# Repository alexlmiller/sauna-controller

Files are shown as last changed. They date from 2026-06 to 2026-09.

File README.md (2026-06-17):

# Local & Smart Sauna Controller

Open-source sauna convenience control built around ESPHome and Home Assistant. Control your sauna from anywhere with no cloud dependencies or crappy apps and for 1/3rd the cost of the normal commercial units.

The project can be built two ways:

- **Build from components**: hand-wire off-the-shelf modules and DIN parts.
- **Build with the carrier PCB**: use the Rev B control board PCB for cleaner
  wiring and integrated low-voltage distribution.

Both current build paths use the same Rev B firmware and pin map. The optional
wall panel uses an Elecrow CrowPanel 2.1" rotary display over a short wired UART
link, with a WiFi/Home Assistant panel target available for desk testing.

## Safety

This project is for **convenience control only**. It is not a primary safety
system and must not replace the sauna heater's listed safety controls.

- Use only properly rated, UL/ETL/listed components where applicable.
- Use a heater that already has its required high-limit and safety systems.
- Have the enclosure, high-voltage wiring, grounding, overcurrent protection,
  conductor sizing, strain relief, and final installation reviewed and installed
  by a qualified electrician.
- Do not rely on ESPHome, Home Assistant, WiFi, the wall panel, or this PCB as
  life-safety equipment.

Read [`docs/SAFETY.md`](docs/SAFETY.md) before building.

Controller Box

## What It Controls

- Heater contactor with a 24 VDC coil
- Two DS18B20 temperature probes: ceiling and bench
- Door reed switch
- Manual-reset high-temp circuit in series with the contactor coil
- Relay feedback contact for welded/failed relay detection
- 24 V RGBW LED strip through four PWM MOSFET channels
- Optional wall panel over direct 3.3 V UART

## User Interface

The controller exposes its entities through Home Assistant and can also be used
from a phone dashboard or the optional wall panel.

### Home Assistant Device Page

Home Assistant device page

### Phone Dashboard

Home Assistant phone dashboard

## Build Paths

### Option 1: Build From Components

Use an ESP32 DevKitC, MOSFET driver modules, opto input modules, DIN power
supplies, fusing/protection, and terminal blocks. This is best for prototyping
or a one-off hand-wired build.

Start here: [`docs/BUILD-FROM-COMPONENTS.md`](docs/BUILD-FROM-COMPONENTS.md)

### Option 2: Build With the Carrier PCB

Use the Rev B control board carrier PCB. This is the preferred path for new
installs because it reduces point-to-point wiring and integrates the ESP32
carrier, output drivers, opto inputs, PTC protection, 24 V distribution, 5 V
conversion, and field terminals.

Start here: [`docs/BUILD-WITH-CARRIER-PCB.md`](docs/BUILD-WITH-CARRIER-PCB.md)

The design philosophy and current hardware rationale are summarized in
[`docs/DESIGN.md`](docs/DESIGN.md).

## Firmware

Current build targets:

```bash
# Control board
esphome run firmware/control-board/rev-b.yaml

# Normal wired wall panel
esphome run firmware/wall-panel/wired.yaml

# WiFi/Home Assistant wall panel for desk testing
esphome run firmware/wall-panel/wifi.yaml
```

See [`docs/FIRMWARE.md`](docs/FIRMWARE.md) for secrets setup, target layout,
and the legacy Rev A note.

## Wall Panel

The wall panel is optional. The normal installation uses direct 3.3 V UART over
a short Cat5e run and gets 5 V power from the control board. The control board
remains the source of truth for temperature, faults, heat mode, and lighting.

See [`docs/WALL-PANEL.md`](docs/WALL-PANEL.md).

## More Detail

- [`docs/DESIGN.md`](docs/DESIGN.md): design choices and source-of-truth paths.
- [`docs/SAFETY.md`](docs/SAFETY.md): safety boundaries and installation notes.
- [`docs/FIRMWARE.md`](docs/FIRMWARE.md): ESPHome targets and package layout.
- [`docs/WALL-PANEL.md`](docs/WALL-PANEL.md): optional panel behavior and wiring.
- [`pcb/rev-b/README.md`](pcb/rev-b/README.md): KiCad, fabrication, assembly,
  and board verification details.

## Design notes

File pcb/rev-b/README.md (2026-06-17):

# Rev B Control Board PCB

Complete KiCad design for the Rev B sauna control board. The board carries an
ESP32 DevKitC V4, switches the low-voltage outputs, senses the low-voltage
inputs, distributes 24 V/5 V, and terminates the field wiring cleanly.

This board is part of a **convenience-control** project only. It does not
replace the heater's listed safety systems, required high-limit controls,
proper overcurrent protection, grounding, or code-compliant high-voltage
installation. Use UL/ETL/listed components where applicable and have the final
enclosure and wiring reviewed and installed by a qualified electrician.

For installation-level instructions, start with
[`../../docs/BUILD-WITH-CARRIER-PCB.md`](../../docs/BUILD-WITH-CARRIER-PCB.md).
For design rationale, see [`../../docs/DESIGN.md`](../../docs/DESIGN.md).

## Board Summary

- 120.76 x 88 mm, 2-layer, 1 oz outer copper, 5 mm corner radius, 4x M3 corner
  holes.
- ESP32 DevKitC V4 socket, using ESP32-WROOM-32E or ESP32-WROOM-32D only. Do
  not use WROVER DevKitC variants because Rev B uses GPIO16/GPIO17.
- 24 V input distribution, 24 V to 5 V conversion, and resettable PTC branch
  protection.
- Low-side MOSFET outputs for relay coil, RGBW LEDs, and optional AUX output
  hardware.
- Opto-isolated relay-feedback and high-temp status inputs.
- Separate DS18B20 buses for bench and ceiling sensors.
- Direct 3.3 V UART wall-panel connector with 5 V panel power.

## Connector Layout

The placement follows the cabinet wiring:

| Edge | Connectors | Reason |
|---|---|---|
| Top | `J_PWR`, `J_AUX_OUT` | 24 V PSU is above the board; AUX output can route with top-side low-voltage wiring |
| Left | `J_LED` | LED branch is the highest current low-voltage path, kept short |
| Bottom | `J_PANEL`, `J_DOOR`, `J_BENCH`, `J_CEILING`, `J_SRL250` | Sauna-room and panel wiring enters along the lower side |
| Right | `J_COIL`, `J_RELAY_FB` | Contactor sits to the right, so coil and monitor wiring stay short |

## Key Electrical Choices

- The contactor coil is low-side switched on the board, but heater power stays
  on the external contactor.
- The manual-reset high-temp loop is in series with the contactor coil and is
  also sensed through an opto input.
- Relay feedback uses the contactor auxiliary contact through an opto input.
- RGBW LED outputs are low-side switched and include gate-sensed activity LEDs.
- The optional AUX output is exposed by Rev B firmware as `AUX Output`.
- The on-board FAULT LED follows the firmware's latched fault state.
- The 5 V rail uses a K7805-2000R3 SIP-3 buck converter.
- The board uses a B.Cu ground plane and net classes defined in
  [`tools/design.py`](tools/design.py).

## Files

| File | Purpose |
|---|---|
| `sauna-rev-b.kicad_pro` | KiCad project and design rules |
| `sauna-rev-b.kicad_sch` | Generated schematic |
| `sauna-rev-b.kicad_pcb` | Hand-routed board generated from source plus captured routing |
| `tools/design.py` | Source of truth for nets, parts, pin mapping, and placement |
| `tools/routing.py` | Captured KiCad routing |
| `tools/footprints.py` | Local footprint geometry |
| `tools/generate_schematic.py` | Regenerates the schematic |
| `tools/generate_board.py` | Regenerates the PCB from design data and routing |
| `tools/import_routing.py` | Captures hand-routed traces from KiCad |
| `tools/generate_bom.py` | Regenerates assembly BOM |
| `tools/export_fabrication.py` | Regenerates BOM, CPL, Gerbers, drills, and upload zip |
| `tools/_repro_check.py` | Verifies generated board content matches the checked-in PCB |
| `tools/check_board.py` | Checks clearances and connectivity |
| `fabrication/` | Current fabrication and assembly outputs |

## Edit Workflow

Routing and final placement are edited in KiCad, then captured back into the
generator inputs. After KiCad edits:

```bash
cd pcb/rev-b
python3 -m venv .venv && .venv/bin/pip install kiutils numpy
.venv/bin/python tools/import_routing.py
.venv/bin/python tools/_design_diff.py
.venv/bin/python tools/_silk_diff.py
.venv/bin/python tools/_repro_check.py
.venv/bin/python tools/generate_board.py
.venv/bin/python tools/check_board.py
```

Before ordering, also run KiCad ERC/DRC locally with zones filled.

## Assembly Notes

The Rev B board is intended to be supplier-assembled, including terminal blocks,
ESP sockets, electrolytics, K7805 buck, and resettable PTCs. The generated
assembly files are in [`fabrication/`](fabrication/).

Current notable JLC/LCSC selections include:

- AOD4184A MOSFETs: `C99124`
- SS54 Schottky diodes: `C22452`
- SMBJ30CA TVS diodes: `C5331115`
- F1 LED PTC: `C719172`
- F4 AUX PTC: `C139284`

Verify stock, polarity, substitutions, and physical fit before ordering. Print
the board 1:1 and test-fit the DevKitC, terminal blocks, PTCs, K7805, SOP-4
opto parts, and electrolytic capacitors.

## Verification

Machine checks in this repo cover courtyard overlaps, board boundary, antenna
keepout, per-net-class copper/edge clearance, and single-island connectivity.

Before installing a fabricated board:

1. Inspect polarity, soldering, terminal labels, and ESP32 orientation.
2. Confirm 24 V input, 5 V output, and 3.3 V ESP rail with no field loads.
3. Bench-test relay-feedback and high-temp opto channels with 24 V.
4. Test each LED channel with a current-limited load.
5. Test contactor coil control before energizing the heater circuit.

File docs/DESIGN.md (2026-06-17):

# Design Notes

This file captures the durable design rationale for the current sauna
controller. It intentionally avoids copying large YAML or KiCad details; the
live source files listed below are authoritative.

## Source Of Truth

- Control board firmware: [`../firmware/control-board/rev-b.yaml`](../firmware/control-board/rev-b.yaml)
- Shared control logic: [`../firmware/control-board/packages/common.yaml`](../firmware/control-board/packages/common.yaml)
- Wall panel firmware: [`../firmware/wall-panel/`](../firmware/wall-panel/)
- Rev B board design: [`../pcb/rev-b/`](../pcb/rev-b/)
- Rev B board database: [`../pcb/rev-b/tools/design.py`](../pcb/rev-b/tools/design.py)

## Safety Boundary

The project is for convenience control only. The heater must have its own
listed safety systems, and the manual-reset high-temp loop stays in series with
the contactor coil so it can interrupt heat without software.

The control board should fail with heat off if the ESP32 reboots, firmware
crashes, WiFi drops, Home Assistant is unavailable, or the wall panel is
unplugged. That fail-off behavior is useful, but it is not a substitute for a
listed safety system or code-compliant installation.

## Hardware Philosophy

- Keep high-voltage switching outside the PCB. The board controls a 24 VDC
  contactor coil; the contactor handles heater power.
- Use a 24 V low-voltage cabinet bus for field wiring, contactor coil, opto
  wetting loops, LED strip power, and auxiliary loads.
- Generate 5 V on the carrier board for the ESP32 DevKitC and optional wall
  panel.
- Keep the ESP32 as a socketed DevKitC module instead of placing the ESP32
  module directly on the carrier board. This avoids RF layout, USB, boot strap,
  and assembly complexity.
- Use the Espressif ESP32-DevKitC V4 with an ESP32-WROOM-32E or WROOM-32D
  module. Do not use WROVER DevKitC variants on Rev B because GPIO16/GPIO17 are
  used by the board.
- Prefer grouped, field-serviceable connectors over minimum board area. The
  connector placement follows the physical cabinet: 24 V supply at the top,
  sauna-room wiring along the bottom, LEDs on the left, and contactor wiring on
  the right.
- Use resettable PTC protection on the low-voltage board branches instead of
  external DIN fuse holders.

## Control Model

The control board owns the heater, faults, sensors, and outputs. Home Assistant
and the wall panel request state changes; they are not required for the board to
run its local control logic.

The wall panel is a client. On boot it syncs from the control board before
publishing user changes, so it does not overwrite Home Assistant or control
board state with stale defaults.

## Current GPIO Map

The authoritative map is the `substitutions:` block in
[`../firmware/control-board/rev-b.yaml`](../firmware/control-board/rev-b.yaml).
For a hand-wired build, wire to that file rather than an older Rev A pin list.

Rev B uses:

| Function | GPIO |
|---|---:|
| Relay coil MOSFET | 23 |
| LED R/G/B/W | 19 / 18 / 17 / 16 |
| Door reed | 25 |
| Bench / ceiling DS18B20 | 26 / 27 |
| Relay feedback | 34 |
| High-temp trip status | 35 |
| Wall panel UART TX / RX | 32 / 33 |
| Fault LED | 22 |
| AUX output | 4 |

GPIO34 and GPIO35 are input-only and do not have internal pull-ups. The Rev B
carrier provides the required input conditioning; a hand-wired component build
must do the same.

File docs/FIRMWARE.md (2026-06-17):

# Firmware

Current builds use the Rev B firmware targets.

## Targets

```bash
# Control board
esphome run firmware/control-board/rev-b.yaml

# Wired wall panel
esphome run firmware/wall-panel/wired.yaml

# WiFi/Home Assistant wall panel for desk testing
esphome run firmware/wall-panel/wifi.yaml
```

## Secrets

Create a root `secrets.yaml` with:

```yaml
wifi_ssid: "..."
wifi_password: "..."
wifi_fallback_pw: "..."
ota_password: "..."
api_key: "..."
syslog_host: "..."
```

The firmware folders contain relative `secrets.yaml` symlinks so ESPHome can
resolve `!secret` after the targets were moved into subdirectories. The real
root `secrets.yaml` is ignored by Git.

## Control Board Pins

The current pin map lives in the `substitutions:` block of
[`../firmware/control-board/rev-b.yaml`](../firmware/control-board/rev-b.yaml).
That file is the source of truth for both carrier-PCB and hand-wired Rev B
builds.

Rev B deliberately changed several Rev A pins to make the board route cleanly:
the relay coil is on GPIO23, the wall-panel UART is on GPIO32/GPIO33, the door
input is on GPIO25, relay feedback and high-temp status are on GPIO34/GPIO35,
and the RGBW LED channels are ordered GPIO19/GPIO18/GPIO17/GPIO16.

Rev B also includes [`../firmware/control-board/packages/rev-b-hardware.yaml`](../firmware/control-board/packages/rev-b-hardware.yaml),
which drives the on-board FAULT LED from GPIO22 and exposes GPIO4 as the
`AUX Output` switch. That package is included only by the Rev B control-board
target.

## Layout

```text
firmware/
  control-board/
    rev-b.yaml
    packages/common.yaml

  wall-panel/
    wired.yaml
    wifi.yaml
    packages/

  legacy/rev-a/
```

The control board owns safety and actuator control. The wall panel sends
requests and displays status but is not required for safe operation.

## Legacy Rev A

Rev A firmware wrappers are kept in [`firmware/legacy/rev-a/`](../firmware/legacy/rev-a/)
for early boards only. New component and carrier-PCB builds should use Rev B.

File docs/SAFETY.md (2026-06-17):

# Safety

This project is for **convenience control only**. It can command a contactor,
read sensors, manage lighting, and expose controls through Home Assistant or a
wall panel. It is not a primary safety system.

## Requirements

- Use a sauna heater that already includes its required safety systems.
- Keep the heater's listed/manual-reset high-limit and required thermal
  protections in place.
- Use UL/ETL/listed components where applicable, including the contactor, power
  supply, enclosure, terminal blocks, fuses/breakers, conductors, and glands.
- Size conductors, fuses, breakers, contactors, terminals, and enclosures for
  the actual heater load and installation environment.
- Keep high-voltage and low-voltage wiring physically separated.
- Bond and ground the enclosure and heater according to local code.
- Have the final design, enclosure, wiring, overcurrent protection, grounding,
  and installation reviewed and installed by a qualified electrician.

## Do Not Rely On

Do not rely on any of the following as life-safety equipment:

- ESPHome firmware
- Home Assistant
- WiFi
- The wall panel
- The custom carrier PCB
- Software temperature limits
- Relay feedback monitoring

The manual-reset high-temp loop and the heater's own listed safety systems must
remain the safety backstop.

## Design Intent

The control board should fail with the heater off when the ESP32 reboots,
firmware crashes, WiFi drops, Home Assistant is unavailable, or the wall panel
is unplugged. That fail-off behavior is useful, but it still does not make the
project a code-approved primary safety system.

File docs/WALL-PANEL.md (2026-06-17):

# Wall Panel

The wall panel is an optional local interface based on the Elecrow CrowPanel
2.1" rotary display. It is not the safety controller; the control board remains
the source of truth.

## Normal Wired Build

- Direct 3.3 V UART over a short Cat5e run
- Control board UART: GPIO32 TX / GPIO33 RX
- Wall panel UART: GPIO43 TX / GPIO44 RX
- 5 V power from the control board
- WiFi remains available for OTA updates

Firmware:

```bash
esphome run firmware/wall-panel/wired.yaml
```

## WiFi Desk-Test Build

The WiFi/Home Assistant target is useful for UI testing without the wired UART
link:

```bash
esphome run firmware/wall-panel/wifi.yaml
```

## Behavior

- Heater page: current temperature, target temperature, heater state, fault
  banner.
- Lights page: brightness and preset control.
- Status page: ceiling/bench temperatures, door, heater, high-temp, relay
  feedback, and clear-fault control.

## Control Model

The control board remains authoritative. The panel displays exported control
board state and sends commands for target temperature, heat mode, lights, and
fault clearing.

The panel suppresses command publishing until it has synced from the control
board, so it should not overwrite Home Assistant changes on boot. The live
implementation is in:

- [`../firmware/wall-panel/packages/common.yaml`](../firmware/wall-panel/packages/common.yaml)
- [`../firmware/wall-panel/packages/wired.yaml`](../firmware/wall-panel/packages/wired.yaml)
- [`../firmware/wall-panel/packages/wifi.yaml`](../firmware/wall-panel/packages/wifi.yaml)
- [`../firmware/control-board/packages/common.yaml`](../firmware/control-board/packages/common.yaml)

## UART Notes

The installed Rev B design uses direct 3.3 V UART, not RS-485. That choice keeps
the panel wiring simple and has been sufficient for the short in-cabinet to
wall-panel run. Revisit RS-485 only if the direct UART link proves unreliable in
a specific installation.

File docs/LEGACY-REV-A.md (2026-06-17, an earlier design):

# Legacy Rev A

Rev A was an early board/hand-wired compatibility target. It is kept only for
the few existing early systems.

New builds should use:

- [`firmware/control-board/rev-b.yaml`](../firmware/control-board/rev-b.yaml)
- [`firmware/wall-panel/wired.yaml`](../firmware/wall-panel/wired.yaml)
- [`firmware/wall-panel/wifi.yaml`](../firmware/wall-panel/wifi.yaml)

Legacy files:

- [`firmware/legacy/rev-a/control-board.yaml`](../firmware/legacy/rev-a/control-board.yaml)
- [`firmware/legacy/rev-a/wall-panel-wired.yaml`](../firmware/legacy/rev-a/wall-panel-wired.yaml)
- [`firmware/legacy/rev-a/wall-panel-wifi.yaml`](../firmware/legacy/rev-a/wall-panel-wifi.yaml)

Do not use these for a new self-assembled or carrier-PCB build unless you are
intentionally matching an existing Rev A installation.

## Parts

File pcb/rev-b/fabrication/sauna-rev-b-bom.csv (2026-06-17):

Comment | Designator | Footprint | JLCPCB Part #
ESP_ROW_3V3 | J_ESP1 | 1x19 2.54mm female header | C319202
ESP_ROW_GND23 | J_ESP2 | 1x19 2.54mm female header | C319202
100nF | C3,C5,C7,C8,C9,C10 | C0805 | C49678
10uF 50V | C1 | C1210 | C138687
22uF 25V | C2 | C1210 | C52306
GREEN 24V | LED1 | LED0805 | C2297
GREEN 5V | LED2 | LED0805 | C2297
RED ACT | LED4,LED5,LED6,LED7 | LED0805 | C2295
RED FAULT | LED3 | LED0805 | C2295
750mA PTC (COIL) | F2 | PTC1812 | C208467
750mA PTC (LOGIC) | F3 | PTC1812 | C208467
2A PTC (AUX) | F4 | PTC2920 | C139284
3A PTC (LED) | F1 | PTC2920 | C719172
100R | R7,R8,R9,R10,R11,R21,R22,R23,R24,R32 | R0805 | C17408
10K | R4,R5,R12,R13,R14,R15,R16,R17,R25,R33 | R0805 | C17414
1K | R18,R26,R27,R28,R29,R30,R31 | R0805 | C17513
4K7 | R19,R20 | R0805 | C17673
3K3 | R1,R2 | R1206 | C104771
750mA PTC | PF1 | R1812 | C208467
220uF 50V | C4,C6 | Radial D8.0mm P3.50mm | C106658
K7805-2000R3 | U1 | SIP-3,2.54mm | C18212380
SS54 | D5,D11 | SMA,DO-214AC | C22452
SMBJ30CA | D2,D3 | SMB,DO-214AA | C5331115
SMBJ33A | D1 | SMB,DO-214AA | C78419
1N4148WS | D9,D10 | SOD-323 | C2128
ESD9B5.0 | D6,D7,D8 | SOD-923 | C111566
LTV-817S | OPT_RELAY_FB,OPT2 | SOP-4 | C109227
USBLC6-2SC6 | U2 | SOT-23-6 | C7519
AOD4184A | Q1,Q2,Q3,Q4,Q5,Q6 | TO-252-2,DPAK | C99124
24V_IN | J_PWR | Terminal 5.08mm 2P | C8461
AUX_OUT | J_AUX_OUT | Terminal 5.08mm 2P | C8461
COIL | J_COIL | Terminal 5.08mm 2P | C8461
DOOR | J_DOOR | Terminal 5.08mm 2P | C8461
RELAY_FB | J_RELAY_FB | Terminal 5.08mm 2P | C8461
SRL250 | J_SRL250 | Terminal 5.08mm 2P | C8461
BENCH_T | J_BENCH | Terminal 5.08mm 3P | C8438
CEIL_T | J_CEILING | Terminal 5.08mm 3P | C8438
PANEL | J_PANEL | Terminal 5.08mm 4P | C8429
LED_RGBW | J_LED | Terminal 5.08mm 5P | C8433

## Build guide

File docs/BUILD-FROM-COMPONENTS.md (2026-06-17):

# Build From Components

This path builds the sauna controller from off-the-shelf modules and DIN parts
instead of the custom carrier PCB. It is useful for prototyping or a one-off
hand-wired build.

New component builds should still use the **Rev B firmware and GPIO map** in
[`firmware/control-board/rev-b.yaml`](../firmware/control-board/rev-b.yaml).
Rev A files are only for early historical boards.

## Safety

This project is for **convenience control only**. Use a heater with its own
listed safety systems, keep the manual-reset high-temp protection in series with
the contactor coil, use UL/ETL/listed components where applicable, and have the
high-voltage wiring and final enclosure reviewed and installed by a qualified
electrician. Read [`SAFETY.md`](SAFETY.md) before building.

## What You Need

Core electronics:

- ESP32 DevKitC-32E with ESP32-WROOM-32E or ESP32-WROOM-32D module
- 24 V DIN power supply
- 24 V to 5 V DC-DC converter for ESP32 and optional wall panel power
- 5 MOSFET driver channels: relay coil, LED R, LED G, LED B, LED W
- 2 opto-isolated 24 V input channels: relay feedback and high-temp status
- 2 DS18B20 temperature probes
- Door reed switch
- Terminal blocks, wire ferrules, DIN rail wiring hardware, and strain relief
- Branch fusing or resettable protection sized for the loads

Sauna/load hardware:

- Properly rated heater contactor with 24 VDC coil
- Compatible auxiliary contact block for relay feedback
- Manual-reset high-temp thermostat, such as SUPCO SRL250
- 24 V RGBW LED strip, aluminum channel, diffuser, and high-temp cable
- Code-compliant enclosure and high-voltage terminal blocks

Optional:

- Elecrow CrowPanel 2.1" rotary display for the wall panel

## Low-Voltage Architecture

- The 24 V DIN supply feeds the contactor coil branch, LED branch, opto wetting
  loops, auxiliary branch if used, and 24 V to 5 V converter.
- The 5 V converter feeds ESP32 `VIN` and, if used, the wall panel.
- All low-voltage returns share a common 0 V reference.
- The contactor coil is switched on the low side by a MOSFET driver.
- RGBW strip channels are switched on the low side by MOSFET drivers.
- Relay feedback and high-temp status are sensed through opto-isolated 24 V
  input modules or equivalent discrete circuits.

## Rev B GPIO Map

Wire the component build to this map so it runs the current firmware. The
authoritative version is the `substitutions:` block in
[`../firmware/control-board/rev-b.yaml`](../firmware/control-board/rev-b.yaml).

| Function | GPIO |
|---|---:|
| Relay coil MOSFET | 23 |
| LED R/G/B/W | 19 / 18 / 17 / 16 |
| Door reed | 25 |
| Bench / ceiling DS18B20 | 26 / 27 |
| Relay feedback | 34 |
| High-temp trip status | 35 |
| Wall panel UART TX / RX | 32 / 33 |
| Fault LED | 22 |
| AUX output | 4 |

GPIO34 and GPIO35 are input-only and do not have internal pull-ups. Your opto
input circuits must provide the required pull-ups or output conditioning.
GPIO22 drives the fault LED, and GPIO4 drives the optional AUX low-side output.

## Wiring Notes

- Put the manual-reset high-temp thermostat in series with the contactor coil
  so it can interrupt heat without software.
- Add flyback suppression across the contactor coil or at the coil driver.
- Fuse/protect the LED branch, coil branch, logic branch, and any auxiliary
  branch based on the actual loads and wire sizes.
- Use shielded/twisted wiring for temperature probes where practical.
- Keep high-voltage wiring away from ESP32, sensor, panel, and low-voltage
  signal wiring.
- Label terminal blocks by function, not just GPIO number.

## Firmware

Flash the control board:

```bash
esphome run firmware/control-board/rev-b.yaml
```

Optional wall panel:

```bash
esphome run firmware/wall-panel/wired.yaml
```

See [`FIRMWARE.md`](FIRMWARE.md) and [`WALL-PANEL.md`](WALL-PANEL.md).

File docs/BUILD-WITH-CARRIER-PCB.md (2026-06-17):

# Build With the Carrier PCB

This is the preferred path for new installs. The Rev B control board carrier
PCB replaces most point-to-point low-voltage module wiring with one organized
board.

## Safety

This project is for **convenience control only**. Use a heater with its own
listed safety systems, keep the manual-reset high-temp protection in series with
the contactor coil, use UL/ETL/listed components where applicable, and have the
high-voltage wiring and final enclosure reviewed and installed by a qualified
electrician. Read [`SAFETY.md`](SAFETY.md) before building.

## What the PCB Includes

- ESP32 DevKitC-32E socket headers
- 24 V input distribution
- 24 V to 5 V conversion for ESP32 and wall panel
- MOSFET outputs for relay coil, RGBW LEDs, and optional AUX output hardware
- Opto inputs for relay feedback and high-temp status
- Resettable PTC branch protection
- DS18B20, door, wall-panel, LED, relay, and high-temp field terminals
- Power/status LEDs and test points

## What You Still Need

- Rev B control board from [`pcb/rev-b/`](../pcb/rev-b/)
- ESP32 DevKitC-32E with ESP32-WROOM-32E or ESP32-WROOM-32D module
- 24 V DIN power supply
- Properly rated heater contactor with 24 VDC coil
- Compatible auxiliary contact block for relay feedback
- Manual-reset high-temp thermostat, such as SUPCO SRL250
- Two DS18B20 temperature probes
- Door reed switch
- 24 V RGBW LED strip, aluminum channel, diffuser, and cable
- Code-compliant enclosure, HV terminal blocks, grounding, and strain relief
- Optional Elecrow CrowPanel 2.1" rotary display for the wall panel

Do not use a WROVER-based DevKitC on the Rev B carrier without changing the PCB
and firmware pin map. Rev B uses GPIO16/GPIO17.

## Board Ordering

Use [`pcb/rev-b/README.md`](../pcb/rev-b/README.md) for KiCad files,
fabrication outputs, BOM/CPL notes, DRC/ERC checklist, and board verification.
That file is the board fabrication and engineering reference; this file is the
installation-oriented build guide.

The rationale behind the board choices is summarized in [`DESIGN.md`](DESIGN.md).

## Field Wiring By Connector

- `24V IN`: external 24 V supply into the board.
- `HIGH TEMP`: sends fused 24 V out to the manual-reset high-temp thermostat and
  receives the return. This loop is in series with the relay coil.
- `RELAY COIL`: connects to the contactor coil.
- `RELAY MONITOR`: connects to the contactor auxiliary contact.
- `LED LIGHTS`: connects to RGBW strip returns plus 24 V LED supply.
- `BENCH TEMP`: bench DS18B20 3-wire connection.
- `CEILING TEMP`: ceiling DS18B20 3-wire connection.
- `DOOR`: reed switch input.
- `CONTROLLER PANEL`: 5 V, GND, TX, RX for the optional wall panel.
- `AUX OUT`: optional protected 24 V low-side output.

`AUX OUT` is exposed as the `AUX Output` switch. The on-board FAULT LED follows
the controller's latched fault state.

## Bring-Up Checklist

1. Inspect polarity, terminal labels, ESP32 orientation, and field wiring before
   applying power.
2. Power the board from 24 V with the heater high-voltage circuit disconnected.
3. Confirm 5 V and 3.3 V rails.
4. Flash [`firmware/control-board/rev-b.yaml`](../firmware/control-board/rev-b.yaml).
5. Confirm both DS18B20 sensors read correctly.
6. Confirm door input changes state.
7. Confirm high-temp and relay feedback inputs with a 24 V bench test.
8. Confirm LED channels one at a time.
9. Confirm contactor coil control with the heater circuit still disconnected.
10. Have the final high-voltage install reviewed and completed by a qualified
    electrician.

## Firmware

```bash
esphome run firmware/control-board/rev-b.yaml
```

Optional wall panel:

```bash
esphome run firmware/wall-panel/wired.yaml
```

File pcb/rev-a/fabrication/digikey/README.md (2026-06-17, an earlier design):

# Digi-Key Hand-Assembly Buy List

This folder tracks the parts that are not being assembled by JLCPCB and need to be sourced separately.

Primary file:

- `sauna-controller-digikey-buy-list.csv`

Assumptions:

- Quantities are based on 5 assembled boards.
- Suggested order quantities include small spares for hand assembly.
- JLCPCB is still expected to assemble the SMD parts and ESP32 socket headers from the assembly BOM.
- The ESP32 DevKitC, external 24 V power supply, contactor, CrowPanel, and field wiring are not included here.

Open decisions before ordering the PCB:

- Terminal blocks are Phoenix MKDS screw terminals matching the current 5.08 mm footprints. WAGO lever terminals were considered but rejected due to cost and footprint mismatch.
- The current fuse footprints are for Schurter OG clip-style holders, not the Schurter OGN block holder. Each fuse uses two clips; each clip has two through-hole legs. That is why each fuse footprint has four holes but only two electrical nodes.
- `C_5V_IN1` is currently shown as 22 uF / 50 V in the design. The practical Digi-Key selection is 10 uF / 50 V in the same 1210 footprint. This is consistent with R-78E-style input filtering guidance, but the schematic/value should be updated to 10 uF / 50 V if we use it.
- F1 was originally marked 7.5A time-delay. Good Digi-Key 5x20 time-delay options are 5 A and 6.3 A. For a roughly 40 W max LED load at 24 V, either is still comfortably above normal load current; pick one and update silkscreen/assembly notes.

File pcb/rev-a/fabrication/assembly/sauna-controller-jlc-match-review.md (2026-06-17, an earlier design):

# JLC BOM Match Review

> **Rev A reference only.** These LCSC/JLC part matches are for the **Rev A**
> board. Rev B uses different parts (resettable PTCs, K7805 buck regulator,
> updated terminal blocks); see [`../../../rev-b/`](../../../rev-b/) and
> `pcb/rev-b/fabrication/` for the current Rev B BOM. Kept for the auto-match
> gotchas, which still apply when ordering.

Reviewed file:

- `/Users/alex/Downloads/sauna-controller-jlc-bom-JLCPCB Assembly Order.xls`

Review date:

- 2026-04-30

## Summary

The JLC dry-run confirmed the most important gating item:

- `J_ESP_L1,J_ESP_R1` matched to `C319202`, a 1x19 2.54 mm through-hole female socket header.

However, JLC's automatic matching made several bad selections. The upload BOM has been updated to force explicit part numbers for the bad or missing matches.

Updated upload file:

- `pcb/fabrication/assembly/sauna-controller-jlc-bom.csv`

## Bad Auto-Matches Found

These should not be accepted from the first JLC match:

- `R_RX1,R_TX1`: JLC matched `C26010`, which is `3.3k`, not `33 ohm`.
- `R_DR_S1,R_GATE_B1,R_GATE_COIL1,R_GATE_G1,R_GATE_R1,R_GATE_W1`: JLC matched a Keystone connector, not a `100 ohm` resistor.
- `F3`: JLC matched a through-hole disposable fuse, not an 1812 resettable PTC.
- `C_BULK1`: JLC matched an SMT `C1812` part with source quantity `0`, not the radial electrolytic footprint.
- `LED_PWR1`: JLC matched a through-hole LED footprint, not an 0805 LED.
- `LED_COIL1`: JLC matched a global-sourcing LED with source quantity `0`; use the explicit 0805 LED part instead.
- `LED_FAULT1`: no match.
- Several resistor groups were left unmatched.

## Explicit Corrections Added

The BOM now forces these candidate part numbers:

- `C_24V1`: `C28323`, Samsung 1uF 50V 0805 MLCC.
- `C_5V_OUT1`: `C45783`, Samsung 22uF 25V 0805 MLCC.
- `C_DR1`: `C1790`, Samsung 100pF 50V C0G 0805 MLCC.
- `C_BULK1`: `C2960384`, HRK 100uF 35V radial electrolytic, D8xL12mm, 3.5mm pitch.
- `F3`: `C151168`, Littelfuse 1812 500mA resettable PTC.
- `LED_COIL1`: `C2296`, yellow 0805 LED used as amber/status.
- `LED_FAULT1`: `C2295`, red 0805 LED.
- `LED_PWR1`: `C2297`, green 0805 LED.
- `R_DR_PU1,R_DS_BENCH1,R_DS_CEILING1,R_LED_COIL1,R_OPT_AUX_LED1,R_OPT_HL_LED1`: `C17673`, 4.7k 1% 0805.
- `R_DR_S1,R_GATE_B1,R_GATE_COIL1,R_GATE_G1,R_GATE_R1,R_GATE_W1`: `C17408`, 100 ohm 1% 0805.
- `R_GPD_B1,R_GPD_COIL1,R_GPD_G1,R_GPD_R1,R_GPD_W1,R_OPT_AUX_PU1,R_OPT_HL_PU1`: `C17414`, 10k 1% 0805.
- `R_LED_FAULT1,R_LED_PWR1`: `C17513`, 1k 1% 0805.
- `R_RX1,R_TX1`: `C17634`, 33 ohm 1% 0805.

## Remaining Open Item

`C_5V_IN1` is still unresolved:

- Requirement: `22uF/50V`
- Footprint: `C_1210_3225Metric`
- First JLC match: no match

Do not silently substitute this part in the upload. The likely options are:

- Find an exact 22uF/50V 1210 JLC-available part in the JLC UI.
- Review whether changing to a stocked 10uF/50V 1210 part is electrically acceptable for the DC/DC input.
- Leave this one part unassembled and hand-solder a 1210 MLCC, if necessary.

## Re-Upload Instructions

Upload again using:

- `pcb/fabrication/sauna-controller-gerbers-drill.zip`
- `pcb/fabrication/assembly/sauna-controller-jlc-bom.csv`
- `pcb/fabrication/assembly/sauna-controller-jlc-all-pos.csv`

Then check:

- `J_ESP_L1,J_ESP_R1` still match to `C319202`.
- No resistor group is matched to a connector or wrong value.
- `F3` is an 1812 resettable PTC, not a through-hole fuse.
- `C_BULK1` is radial through-hole with 3.5 mm pitch.
- All three indicator LEDs are 0805 parts.
- `C_5V_IN1` is either intentionally resolved or intentionally not populated.

## Updated Upload Review - 2026-04-30

Reviewed file:

- `/Users/alex/Downloads/sauna-controller-jlc-review-bom-JLCPCB Assembly Order.xls`

Result:

- The explicit resistor, PTC, and LED part-number corrections were recognized.
- `J_ESP_L1,J_ESP_R1` still matched to `C319202`.
- The export is still not order-ready.

Important process issue:

- The downloaded file name suggests the human review BOM may have been uploaded instead of the upload BOM.
- The JLC export shows odd column interpretation, such as the uploaded `Footprint` field being populated from note text for some rows.
- For JLC upload, use only `sauna-controller-jlc-bom.csv`, not `sauna-controller-jlc-review-bom.csv`.

Remaining issues from the updated match:

- `C_5V_IN1`: still no match.
- `J_AUX1`: no match.
- `J_BENCH1,J_CEILING1,J_COIL1`: no match.
- `J_LED1`: no match.
- `J_PANEL1`: no match.
- `U1`: no match.
- Many key matched parts show quantity/source as `0`, including:
  - SS54 diodes
  - SMBJ30CA TVS parts
  - SOD-323 ESD parts
  - fuse holders
  - ESP socket headers
  - optocouplers
  - MOSFETs
  - resistor groups

Interpretation:

- The part IDs are mostly correct, but the current JLC match export should not be approved.
- Re-upload using the dedicated JLC upload BOM and verify that the matched order quantities are nonzero for every part intended for assembly.

## Latest Upload Review - 2026-04-30 14:48

Reviewed file:

- `/Users/alex/Downloads/sauna-controller-jlc-bom-JLCPCB Assembly Order.xls`

Extracted review CSV:

- `pcb/fabrication/assembly/sauna-controller-jlc-latest-matched-export.csv`
- `pcb/fabrication/assembly/sauna-controller-jlc-latest-issues.csv`

Result:

- The correct JLC upload BOM appears to have been used this time.
- The explicit part-number fixes are recognized.
- Estimated component total shown in the export: `$22.9867` for 5 assembled boards, but this excludes rows still sitting at quantity/source `0`.

Good matched rows with nonzero quantity:

- `C_24V1`: `C28323`
- `C_5V_OUT1`: `C45783`
- `C_BULK1`: `C2960384`
- `C_DR1`: `C1790`
- `F3`: `C151168`
- `J_PANEL1`: `C122715`
- `LED_COIL1`: `C2296`
- `LED_FAULT1`: `C2295`
- `LED_PWR1`: `C2297`
- `U1`: `C22371890`
- `J_LED1`: `C8459`, but source quantity is only `1 JLCPCB`; verify whether JLC can supply enough before approving.

Rows matched but still unconfirmed/not included:

- `D_B1,D_COIL1,D_G1,D_R1,D_REV1,D_W1`: `C22452`
- `D_TVS_IN1,TVS_AUX1,TVS_HL1`: `C5331115`
- `ESD_DR1,ESD_DS_BENCH1,ESD_DS_CEILING1,TVS_5VP1,TVS_RX_PANEL1,TVS_TX_PANEL1`: `C2827694`
- `F1`: `C3204125`
- `F2`: `C3204125`
- `J_AUX1`: `C8383`
- `J_DOOR1`: `C8383`
- `J_PWR1`: `C8383`
- `J_BENCH1,J_CEILING1,J_COIL1`: `C49238`
- `J_ESP_L1,J_ESP_R1`: `C319202`
- `OPT_AUX1,OPT_HL1`: `C160821`
- `Q_B1,Q_COIL1,Q_G1,Q_R1,Q_W1`: `C99124`
- all resistor groups: `C17673`, `C17408`, `C17414`, `C17513`, `C17634`

These rows have the correct-looking part IDs, but the export shows `Qty 0.0` and `Source 0 JLCPCB`. They must be confirmed/selected in the JLC UI and then re-exported/rechecked.

Still no match:

- `C_5V_IN1`, 22uF/50V, 1210.

Do not approve the order until:

- `J_ESP_L1,J_ESP_R1` show nonzero quantity/source.
- all intended SMD and through-hole parts show nonzero quantity/source or are intentionally marked unassembled.
- `C_5V_IN1` is resolved or intentionally excluded.

## Final Match Check - 2026-04-30 14:52

Reviewed file:

- `/Users/alex/Downloads/sauna-controller-jlc-bom-JLCPCB Assembly Order (1).xls`

Extracted files:

- `pcb/fabrication/assembly/sauna-controller-jlc-finalcheck-matched-export.csv`
- `pcb/fabrication/assembly/sauna-controller-jlc-finalcheck-issues.csv`

Result:

- The latest match is substantially better.
- Matched parts now generally correspond to the intended component classes, values, and packages.
- `J_ESP_L1,J_ESP_R1` now show nonzero quantity/source: `C319202`, quantity `10`, source `10 JLCPCB`.
- Estimated component total shown in the export: `$53.8201` for 5 assembled boards.

Proper-looking matches:

- `C_24V1`: `C28323`, 1uF 50V 0805 MLCC.
- `C_5V_OUT1`: `C45783`, 22uF 25V 0805 MLCC, acceptable for the 10V rail requirement.
- `C_BULK1`: `C2960384`, 100uF 35V radial electrolytic, D8xL12mm, 3.5mm pitch.
- `C_DR1`: `C1790`, 100pF 50V C0G 0805 MLCC.
- `D_B1,D_COIL1,D_G1,D_R1,D_REV1,D_W1`: `C22452`, SS54 SMA Schottky diodes.
- `D_TVS_IN1,TVS_AUX1,TVS_HL1`: `C5331115`, SMBJ30CA SMB TVS parts.
- SOD-323 ESD group: `C2827694`, PESD5V0S1BA SOD-323 5V bidirectional ESD/TVS.
- `F3`: `C151168`, 1812 500mA resettable PTC.
- `J_ESP_L1,J_ESP_R1`: `C319202`, 1x19 2.54mm female headers.
- LEDs: `C2296`, `C2295`, `C2297`, 0805 yellow/red/green LEDs.
- `OPT_AUX1,OPT_HL1`: `C160821`, EL817(C)-G DIP-4 optocouplers.
- MOSFETs: `C99124`, AOD4184A TO-252.
- Resistor groups: correct 0805 values `4.7k`, `100`, `10k`, `1k`, `33`.
- `U1`: `C22371890`, R-78E5.0-1.0 compatible 5V 1A SIP DC/DC module.

Remaining blocker:

- `C_5V_IN1`: no match. Leave intentionally unpopulated for hand solder, or select a compatible 1210 MLCC. Do not use the checked electrolytic alternatives unless the PCB footprint is intentionally changed.

Remaining checks before approval:

- `J_LED1`: matched to `C8459`, but source shows `1 JLCPCB` while quantity is `5`; verify enough supply.
- `F1,F2`: verify Schurter fuse holder body and fuse insertion clearance.
- Terminal blocks: verify body style, wire-entry direction, and footprint fit.
- `U1`: verify pinout/lead spacing/height.
- `Q_*`: verify TO-252 pinout/rotation.
- All diodes/LEDs/ESD parts: verify polarity/orientation in JLC placement preview.

## Assembly-Only JLC BOM - 2026-04-30

Created files:

- `pcb/fabrication/assembly/sauna-controller-jlc-assembly-only-bom.csv`
- `pcb/fabrication/assembly/sauna-controller-jlc-assembly-only-pos.csv`
- `pcb/fabrication/assembly/sauna-controller-jlc-not-assembled-bom.csv`

Purpose:

- Have JLC assemble the ESP headers, SMD parts, optocouplers, DC/DC module, PTC, and radial bulk capacitor.
- Do not have JLC assemble the field terminal blocks, 5x20 fuse holders, or unresolved `C_5V_IN1`.

Validation:

- Assembly-only BOM: `20` grouped rows.
- Assembly-only designators: `56`.
- Assembly-only CPL placements: `56`.
- No BOM designators missing from CPL.
- No extra CPL designators.
- No blank JLC part numbers in assembly-only BOM.

Excluded from JLC assembly:

- `C_5V_IN1`
- `F1`, `F2`
- `J_AUX1`
- `J_DOOR1`
- `J_PWR1`
- `J_BENCH1`
- `J_CEILING1`
- `J_COIL1`
- `J_PANEL1`
- `J_LED1`

## Assembly-Only Match Check - 2026-04-30 16:46

Reviewed file:

- `/Users/alex/Downloads/sauna-controller-jlc-assembly-only-bom-JLCPCB Assembly Order.xls`

Extracted file:

- `pcb/fabrication/assembly/sauna-controller-jlc-assembly-only-matched-export.csv`

Result:

- The excluded parts are absent from the assembly quote:
  - `C_5V_IN1`
  - `F1`, `F2`
  - `J_AUX1`, `J_DOOR1`, `J_PWR1`
  - `J_BENCH1`, `J_CEILING1`, `J_COIL1`
  - `J_PANEL1`, `J_LED1`
- `J_ESP_L1,J_ESP_R1` remain included and show nonzero quantity/source: `C319202`, quantity `10`, source `10 JLCPCB`.
- Estimated component total shown in the export: `$35.6629` for 5 assembled boards.

The assembly-only component matches look appropriate:

- MLCCs: correct 0805 values for included capacitors.
- `C_BULK1`: radial electrolytic still included and matched.
- Schottky/TVS/ESD parts: package classes match the PCB footprints.
- `F3`: 1812 resettable PTC.
- ESP headers: 1x19 2.54mm female headers.
- LEDs: 0805 yellow/red/green indicators.
- Optocouplers: DIP-4 EL817-compatible parts.
- MOSFETs: AOD4184A TO-252.
- Resistors: correct 0805 values.
- `U1`: R-78E5.0-1.0 compatible SIP DC/DC module.

Remaining checks before approval:

- In JLC placement preview, verify polarity/orientation for:
  - all LEDs
  - all diodes
  - all TVS/ESD parts
  - all MOSFETs
  - electrolytic `C_BULK1`
- Verify `J_ESP_L1,J_ESP_R1` are vertical female socket headers with 1x19 count and 2.54mm pitch.
- Verify `U1` pinout, height, and orientation.
- Remember the hand-solder list: install `C_5V_IN1`, `F1`, `F2`, and all field terminal blocks after receiving the boards.

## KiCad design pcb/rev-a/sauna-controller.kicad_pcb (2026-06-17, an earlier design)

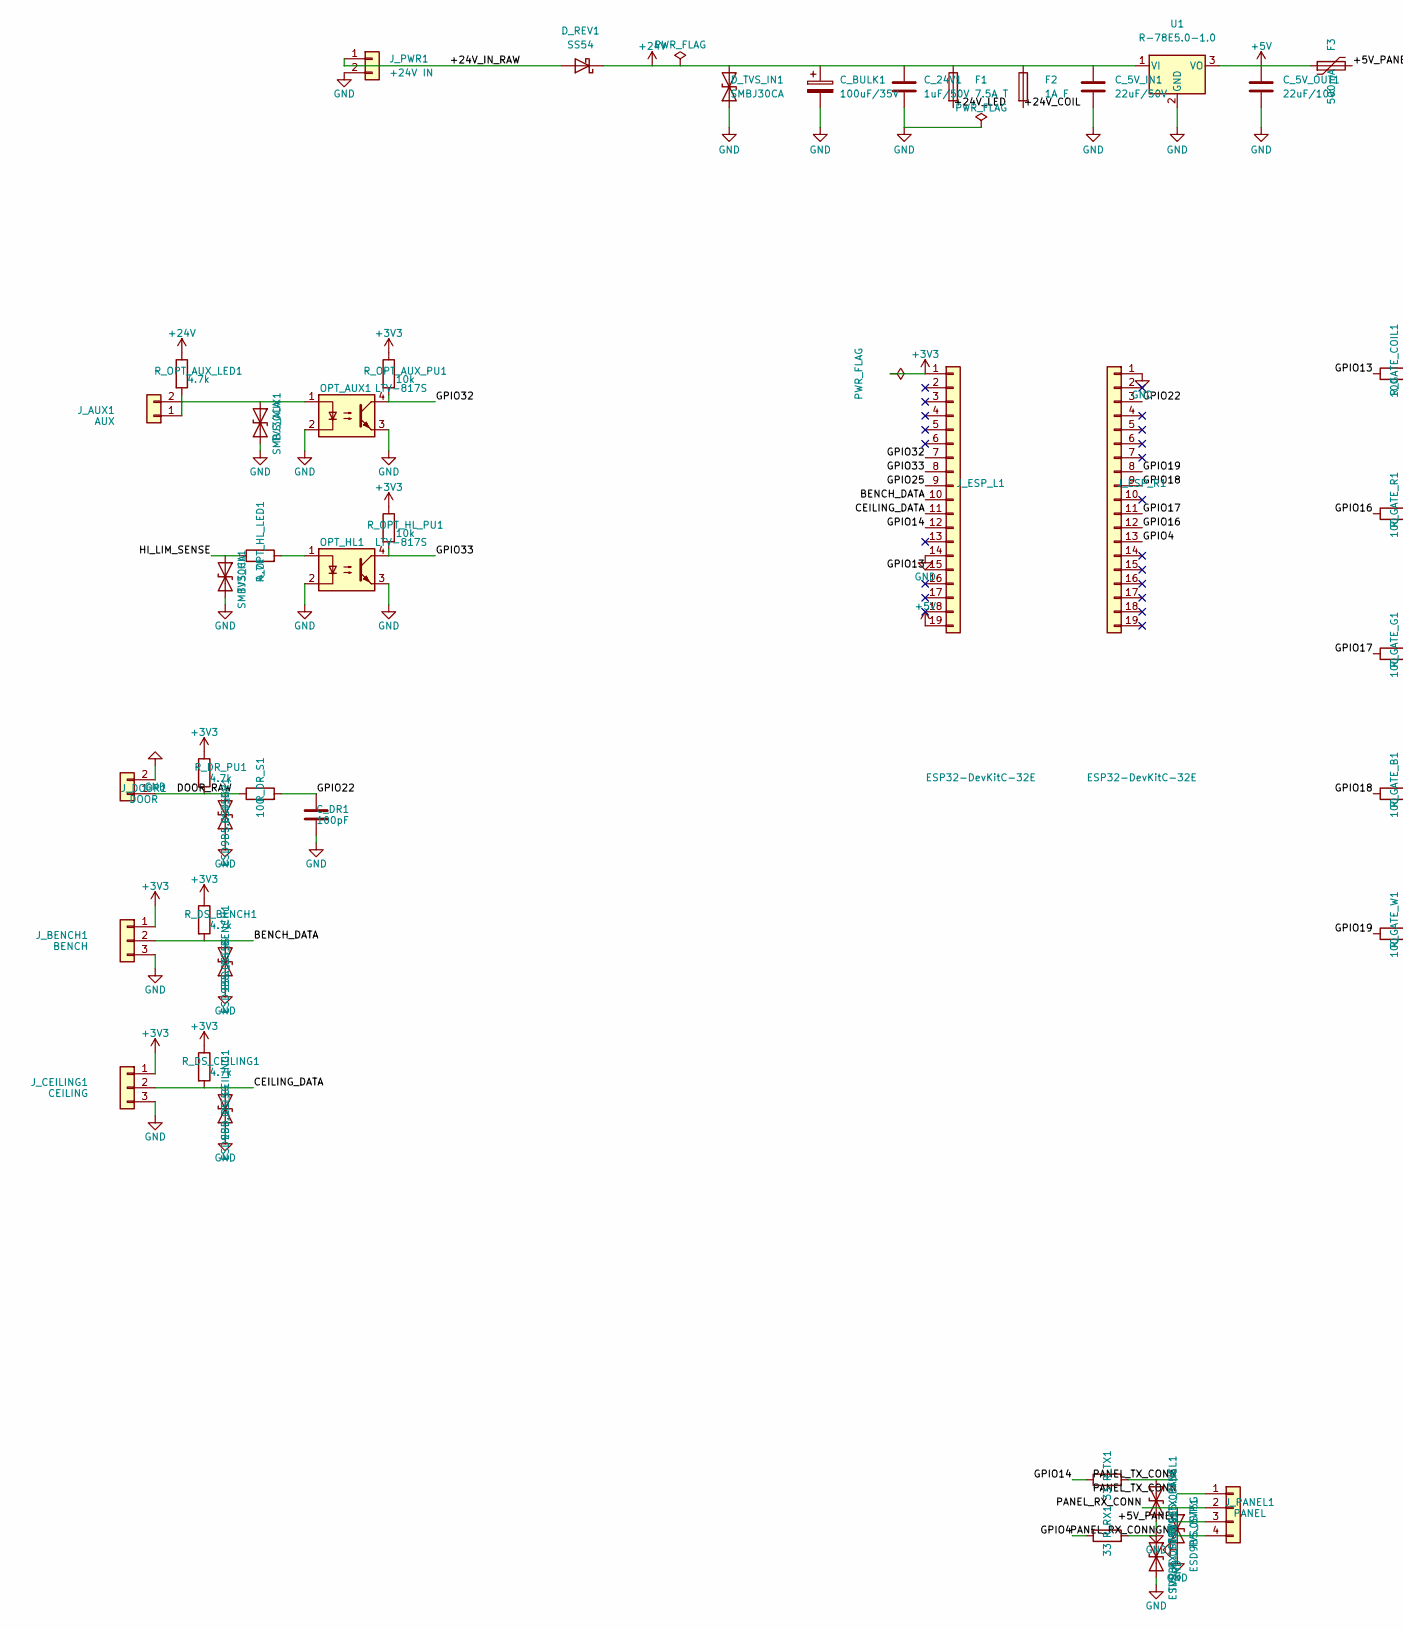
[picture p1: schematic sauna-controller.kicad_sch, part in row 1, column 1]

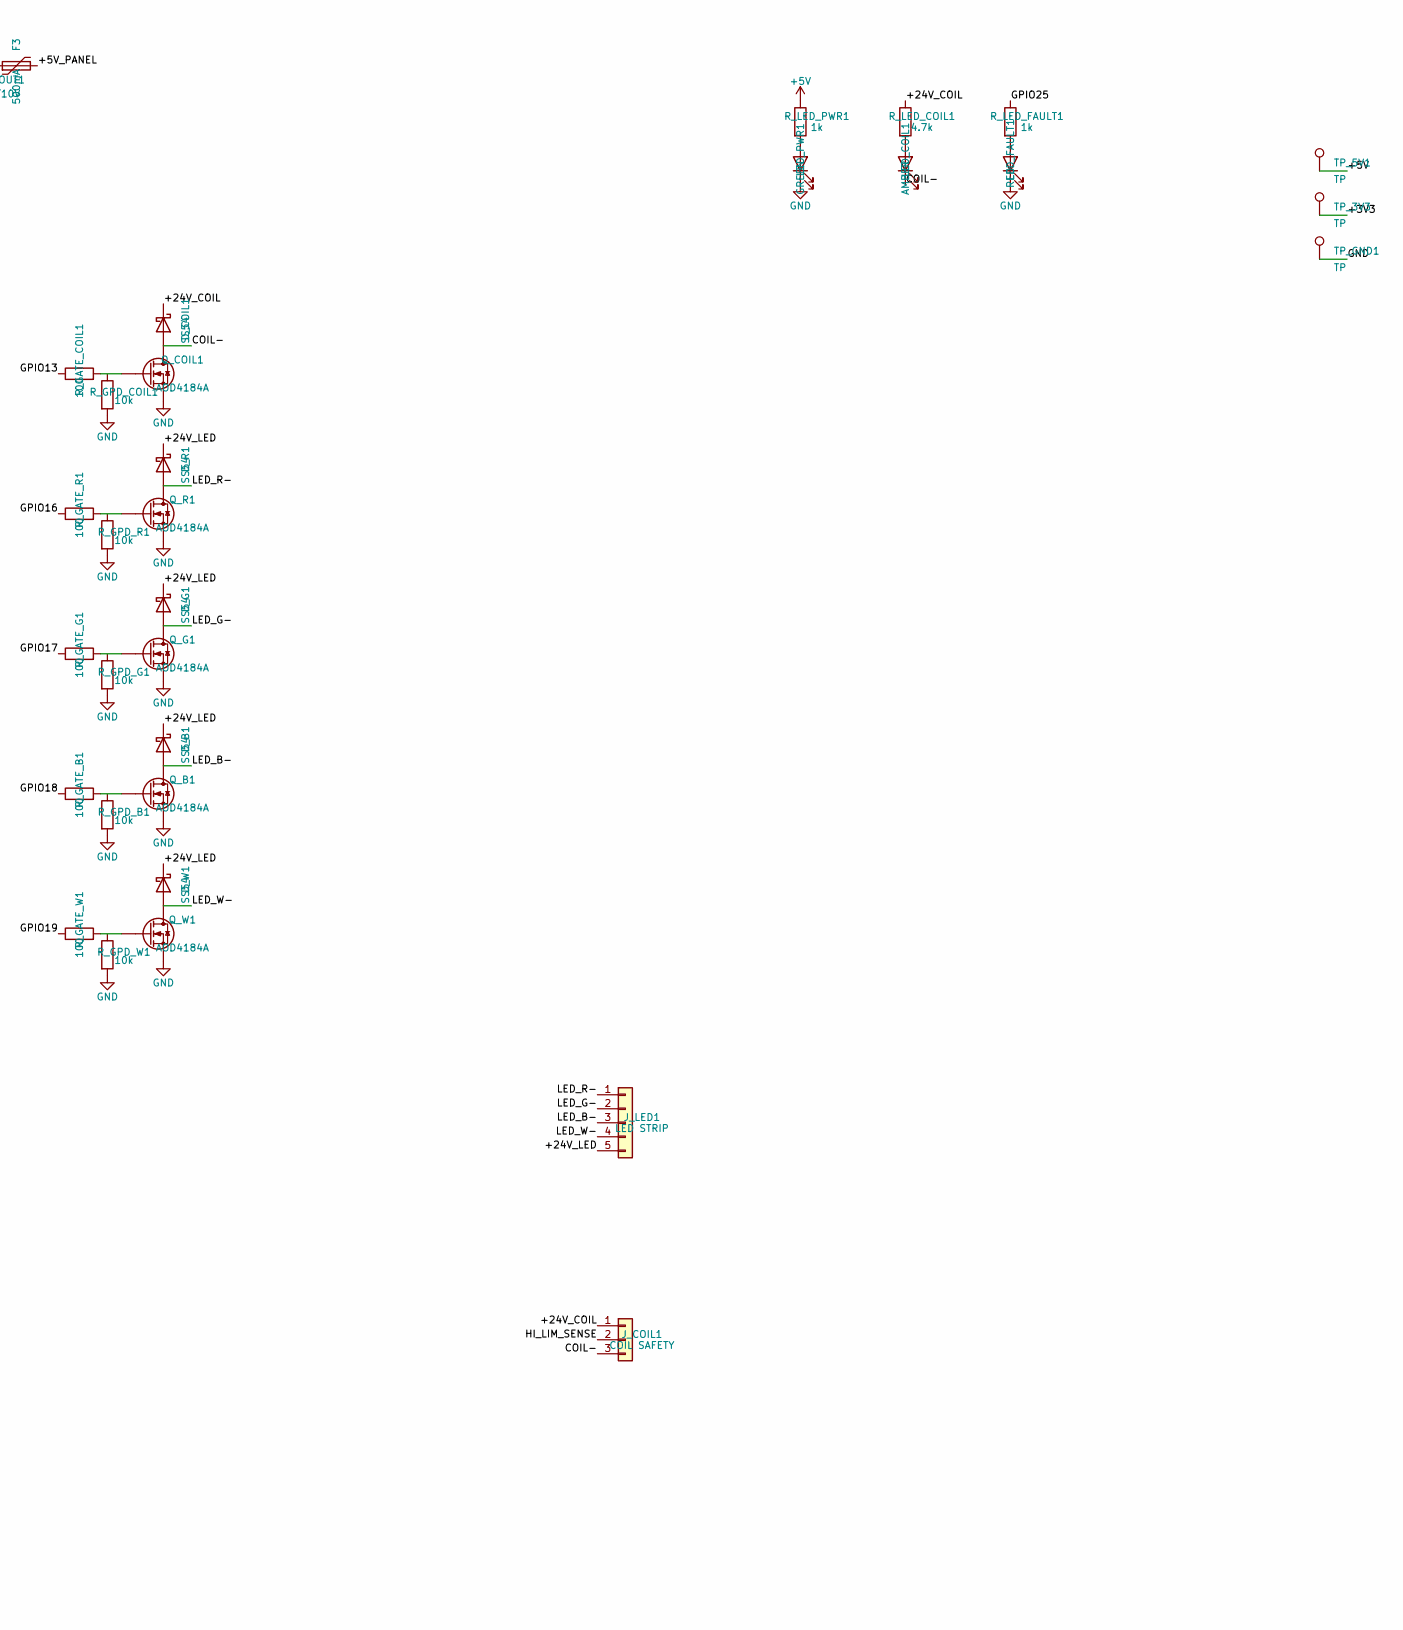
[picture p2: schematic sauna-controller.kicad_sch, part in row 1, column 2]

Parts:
C_5V_IN1: 22uF/50V; C_1210_3225Metric
C_5V_OUT1: 22uF/10V; C_0805_2012Metric
C_24V1: 1uF/50V; C_0805_2012Metric
C_BULK1: 100uF/35V; CP_Radial_D8.0mm_P3.50mm
C_DR1: 100pF; C_0805_2012Metric
D_B1: SS54; D_SMA
D_COIL1: SS54; D_SMA
D_G1: SS54; D_SMA
D_R1: SS54; D_SMA
D_REV1: SS54; D_SMA
D_TVS_IN1: SMBJ30CA; D_SMB
D_W1: SS54; D_SMA
ESD_DR1: ESD9B5.0ST5G; D_SOD-323
ESD_DS_BENCH1: ESD9B5.0ST5G; D_SOD-323
ESD_DS_CEILING1: ESD9B5.0ST5G; D_SOD-323
F1: 7.5A T; Fuseholder_Clip-5x20mm_Schurter_OG_Lateral_P15.00x5.00mm_D1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
F2: 1A F; Fuseholder_Clip-5x20mm_Schurter_OG_Lateral_P15.00x5.00mm_D1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
F3: 500mA; R_1812_4532Metric
J_AUX1: AUX; TerminalBlock_Phoenix_MKDS-1,5-2-5.08_1x02_P5.08mm_Horizont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
J_BENCH1: BENCH; TerminalBlock_Phoenix_MKDS-1,5-3-5.08_1x03_P5.08mm_Horizont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
J_CEILING1: CEILING; TerminalBlock_Phoenix_MKDS-1,5-3-5.08_1x03_P5.08mm_Horizont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
J_COIL1: COIL SAFETY; TerminalBlock_Phoenix_MKDS-1,5-3-5.08_1x03_P5.08mm_Horizont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
J_DOOR1: DOOR; TerminalBlock_Phoenix_MKDS-1,5-2-5.08_1x02_P5.08mm_Horizont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
J_ESP_L1: ESP32-DevKitC-32E; PinSocket_1x19_P2.54mm_Vertical
J_ESP_R1: ESP32-DevKitC-32E; PinSocket_1x19_P2.54mm_Vertical
J_LED1: LED STRIP; TerminalBlock_Phoenix_MKDS-1,5-5-5.08_1x05_P5.08mm_Horizont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
J_PANEL1: PANEL; TerminalBlock_Phoenix_MKDS-1,5-4-5.08_1x04_P5.08mm_Horizont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
J_PWR1: +24V IN; TerminalBlock_Phoenix_MKDS-1,5-2-5.08_1x02_P5.08mm_Horizont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
LED_COIL1: AMBER; LED_0805_2012Metric
LED_FAULT1: RED; LED_0805_2012Metric
LED_PWR1: GREEN; LED_0805_2012Metric
OPT_AUX1: LTV-817S; DIP-4_W7.62mm
OPT_HL1: LTV-817S; DIP-4_W7.62mm
Q_B1: AOD4184A; TO-252-2
Q_COIL1: AOD4184A; TO-252-2
Q_G1: AOD4184A; TO-252-2
Q_R1: AOD4184A; TO-252-2
Q_W1: AOD4184A; TO-252-2
R_DR_PU1: 4.7k; R_0805_2012Metric
R_DR_S1: 100; R_0805_2012Metric
R_DS_BENCH1: 4.7k; R_0805_2012Metric
R_DS_CEILING1: 4.7k; R_0805_2012Metric
R_GATE_B1: 100; R_0805_2012Metric
R_GATE_COIL1: 100; R_0805_2012Metric
R_GATE_G1: 100; R_0805_2012Metric
R_GATE_R1: 100; R_0805_2012Metric
R_GATE_W1: 100; R_0805_2012Metric
R_GPD_B1: 10k; R_0805_2012Metric
R_GPD_COIL1: 10k; R_0805_2012Metric
R_GPD_G1: 10k; R_0805_2012Metric
R_GPD_R1: 10k; R_0805_2012Metric
R_GPD_W1: 10k; R_0805_2012Metric
R_LED_COIL1: 4.7k; R_0805_2012Metric
R_LED_FAULT1: 1k; R_0805_2012Metric
R_LED_PWR1: 1k; R_0805_2012Metric
R_OPT_AUX_LED1: 4.7k; R_0805_2012Metric
R_OPT_AUX_PU1: 10k; R_0805_2012Metric
R_OPT_HL_LED1: 4.7k; R_0805_2012Metric
R_OPT_HL_PU1: 10k; R_0805_2012Metric
R_RX1: 33; R_0805_2012Metric
R_TX1: 33; R_0805_2012Metric
TP_3V3, TP_5V1: TP; TestPoint_Pad_D1.5mm
TP_GND1: TP; TestPoint_Pad_D1.5mm
TVS_5VP1: ESD9B5.0ST5G; D_SOD-323
TVS_AUX1: SMBJ30CA; D_SMB
TVS_HL1: SMBJ30CA; D_SMB
TVS_RX_PANEL1: ESD9B5.0ST5G; D_SOD-323
TVS_TX_PANEL1: ESD9B5.0ST5G; D_SOD-323
U1: R-78E5.0-1.0; Converter_DCDC_RECOM_R-78E-0.5_THT

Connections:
+3V3: J_BENCH1.1, J_CEILING1.1, J_ESP_L1.1, R_DR_PU1.1, R_DS_BENCH1.1, R_DS_CEILING1.1, R_OPT_AUX_PU1.1, R_OPT_HL_PU1.1, TP_3V3.1 (1_1)
+5V: C_5V_OUT1.1, F3.1, J_ESP_L1.19, R_LED_PWR1.1, TP_5V1.1 (1_1), U1.3 (VO)
+24V: C_5V_IN1.1, C_24V1.1, C_BULK1.1, D_REV1.1 (K), D_TVS_IN1.2 (A2), F1.1, F2.1, R_OPT_AUX_LED1.1, U1.1 (VI)
/+5V_PANEL: F3.2, J_PANEL1.3
/+24V_COIL: D_COIL1.1 (K), F2.2, J_COIL1.1, R_LED_COIL1.1
/+24V_IN_RAW: D_REV1.2 (A), J_PWR1.1
/+24V_LED: D_B1.1 (K), D_G1.1 (K), D_R1.1 (K), D_W1.1 (K), F1.2, J_LED1.5
/BENCH_DATA: ESD_DS_BENCH1.2 (A2), J_BENCH1.2, J_ESP_L1.10, R_DS_BENCH1.2
/CEILING_DATA: ESD_DS_CEILING1.2 (A2), J_CEILING1.2, J_ESP_L1.11, R_DS_CEILING1.2
/COIL-: D_COIL1.2 (A), J_COIL1.3, LED_COIL1.1 (K), Q_COIL1.2 (D)
/DOOR_RAW: ESD_DR1.2 (A2), J_DOOR1.1, R_DR_PU1.2, R_DR_S1.1
/GPIO4: J_ESP_R1.13, R_RX1.1
/GPIO13: J_ESP_L1.15, R_GATE_COIL1.1
/GPIO14: J_ESP_L1.12, R_TX1.1
/GPIO16: J_ESP_R1.12, R_GATE_R1.1
/GPIO17: J_ESP_R1.11, R_GATE_G1.1
/GPIO18: J_ESP_R1.9, R_GATE_B1.1
/GPIO19: J_ESP_R1.8, R_GATE_W1.1
/GPIO22: C_DR1.1, J_ESP_R1.3, R_DR_S1.2
/GPIO25: J_ESP_L1.9, R_LED_FAULT1.1
/GPIO32: J_ESP_L1.7, OPT_AUX1.4, R_OPT_AUX_PU1.2
/GPIO33: J_ESP_L1.8, OPT_HL1.4, R_OPT_HL_PU1.2
/HI_LIM_SENSE: J_COIL1.2, R_OPT_HL_LED1.1, TVS_HL1.1 (A1)
/LED_B-: D_B1.2 (A), J_LED1.3, Q_B1.2 (D)
/LED_G-: D_G1.2 (A), J_LED1.2, Q_G1.2 (D)
/LED_R-: D_R1.2 (A), J_LED1.1, Q_R1.2 (D)
/LED_W-: D_W1.2 (A), J_LED1.4, Q_W1.2 (D)
/PANEL_RX_CONN: J_PANEL1.2, R_RX1.2, TVS_5VP1.1 (A1), TVS_RX_PANEL1.1 (A1)
/PANEL_TX_CONN: J_PANEL1.1, R_TX1.2, TVS_TX_PANEL1.1 (A1)
GND: C_5V_IN1.2, C_5V_OUT1.2, C_24V1.2, C_BULK1.2, C_DR1.2, D_TVS_IN1.1 (A1), ESD_DR1.1 (A1), ESD_DS_BENCH1.1 (A1), ESD_DS_CEILING1.1 (A1), J_BENCH1.3, J_CEILING1.3, J_DOOR1.2, J_ESP_L1.14, J_ESP_R1.1, J_PANEL1.4, J_PWR1.2, LED_FAULT1.1 (K), LED_PWR1.1 (K), OPT_AUX1.2, OPT_AUX1.3, OPT_HL1.2, OPT_HL1.3, Q_B1.3 (S), Q_COIL1.3 (S), Q_G1.3 (S), Q_R1.3 (S), Q_W1.3 (S), R_GPD_B1.2, R_GPD_COIL1.2, R_GPD_G1.2, R_GPD_R1.2, R_GPD_W1.2, TP_GND1.1 (1_1), TVS_5VP1.2 (A2), TVS_AUX1.2 (A2), TVS_HL1.2 (A2), TVS_RX_PANEL1.2 (A2), TVS_TX_PANEL1.2 (A2), U1.2 (GND)
unnamed: J_AUX1.1, R_OPT_AUX_LED1.2
unnamed: J_AUX1.2, OPT_AUX1.1, TVS_AUX1.1 (A1)
unnamed: LED_COIL1.2 (A), R_LED_COIL1.2
unnamed: LED_FAULT1.2 (A), R_LED_FAULT1.2
unnamed: LED_PWR1.2 (A), R_LED_PWR1.2
unnamed: OPT_HL1.1, R_OPT_HL_LED1.2
unnamed: Q_B1.1 (G), R_GATE_B1.2, R_GPD_B1.1
unnamed: Q_COIL1.1 (G), R_GATE_COIL1.2, R_GPD_COIL1.1
unnamed: Q_G1.1 (G), R_GATE_G1.2, R_GPD_G1.1
unnamed: Q_R1.1 (G), R_GATE_R1.2, R_GPD_R1.1
unnamed: Q_W1.1 (G), R_GATE_W1.2, R_GPD_W1.1

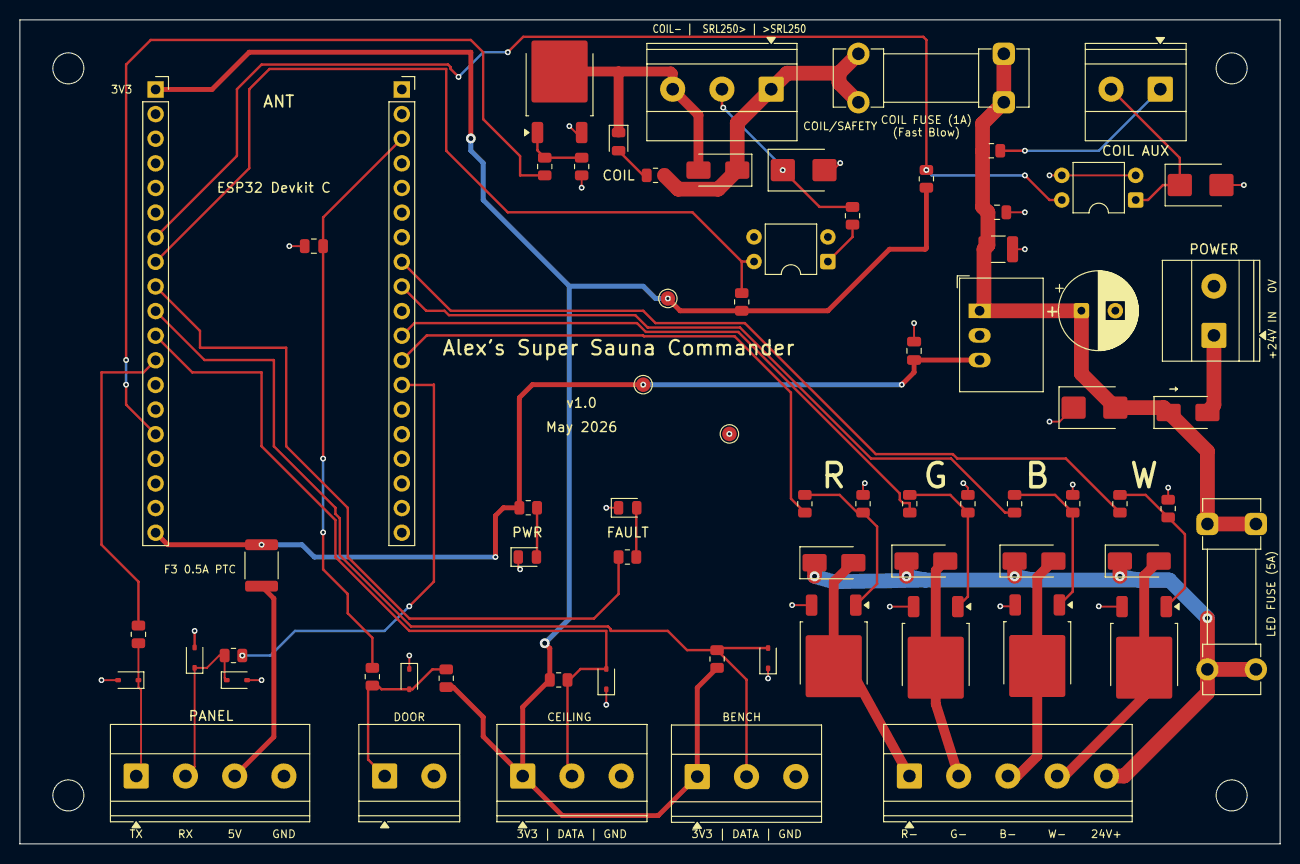
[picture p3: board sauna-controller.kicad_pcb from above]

Board: 2 copper layers, 130.0 x 85.0 mm, 74 parts (0 on the bottom side), 41 nets.

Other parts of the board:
MH1, MH2, MH3, MH4: MountingHole_3.2mm_M3; MountingHole_3.2mm_M3_DIN965

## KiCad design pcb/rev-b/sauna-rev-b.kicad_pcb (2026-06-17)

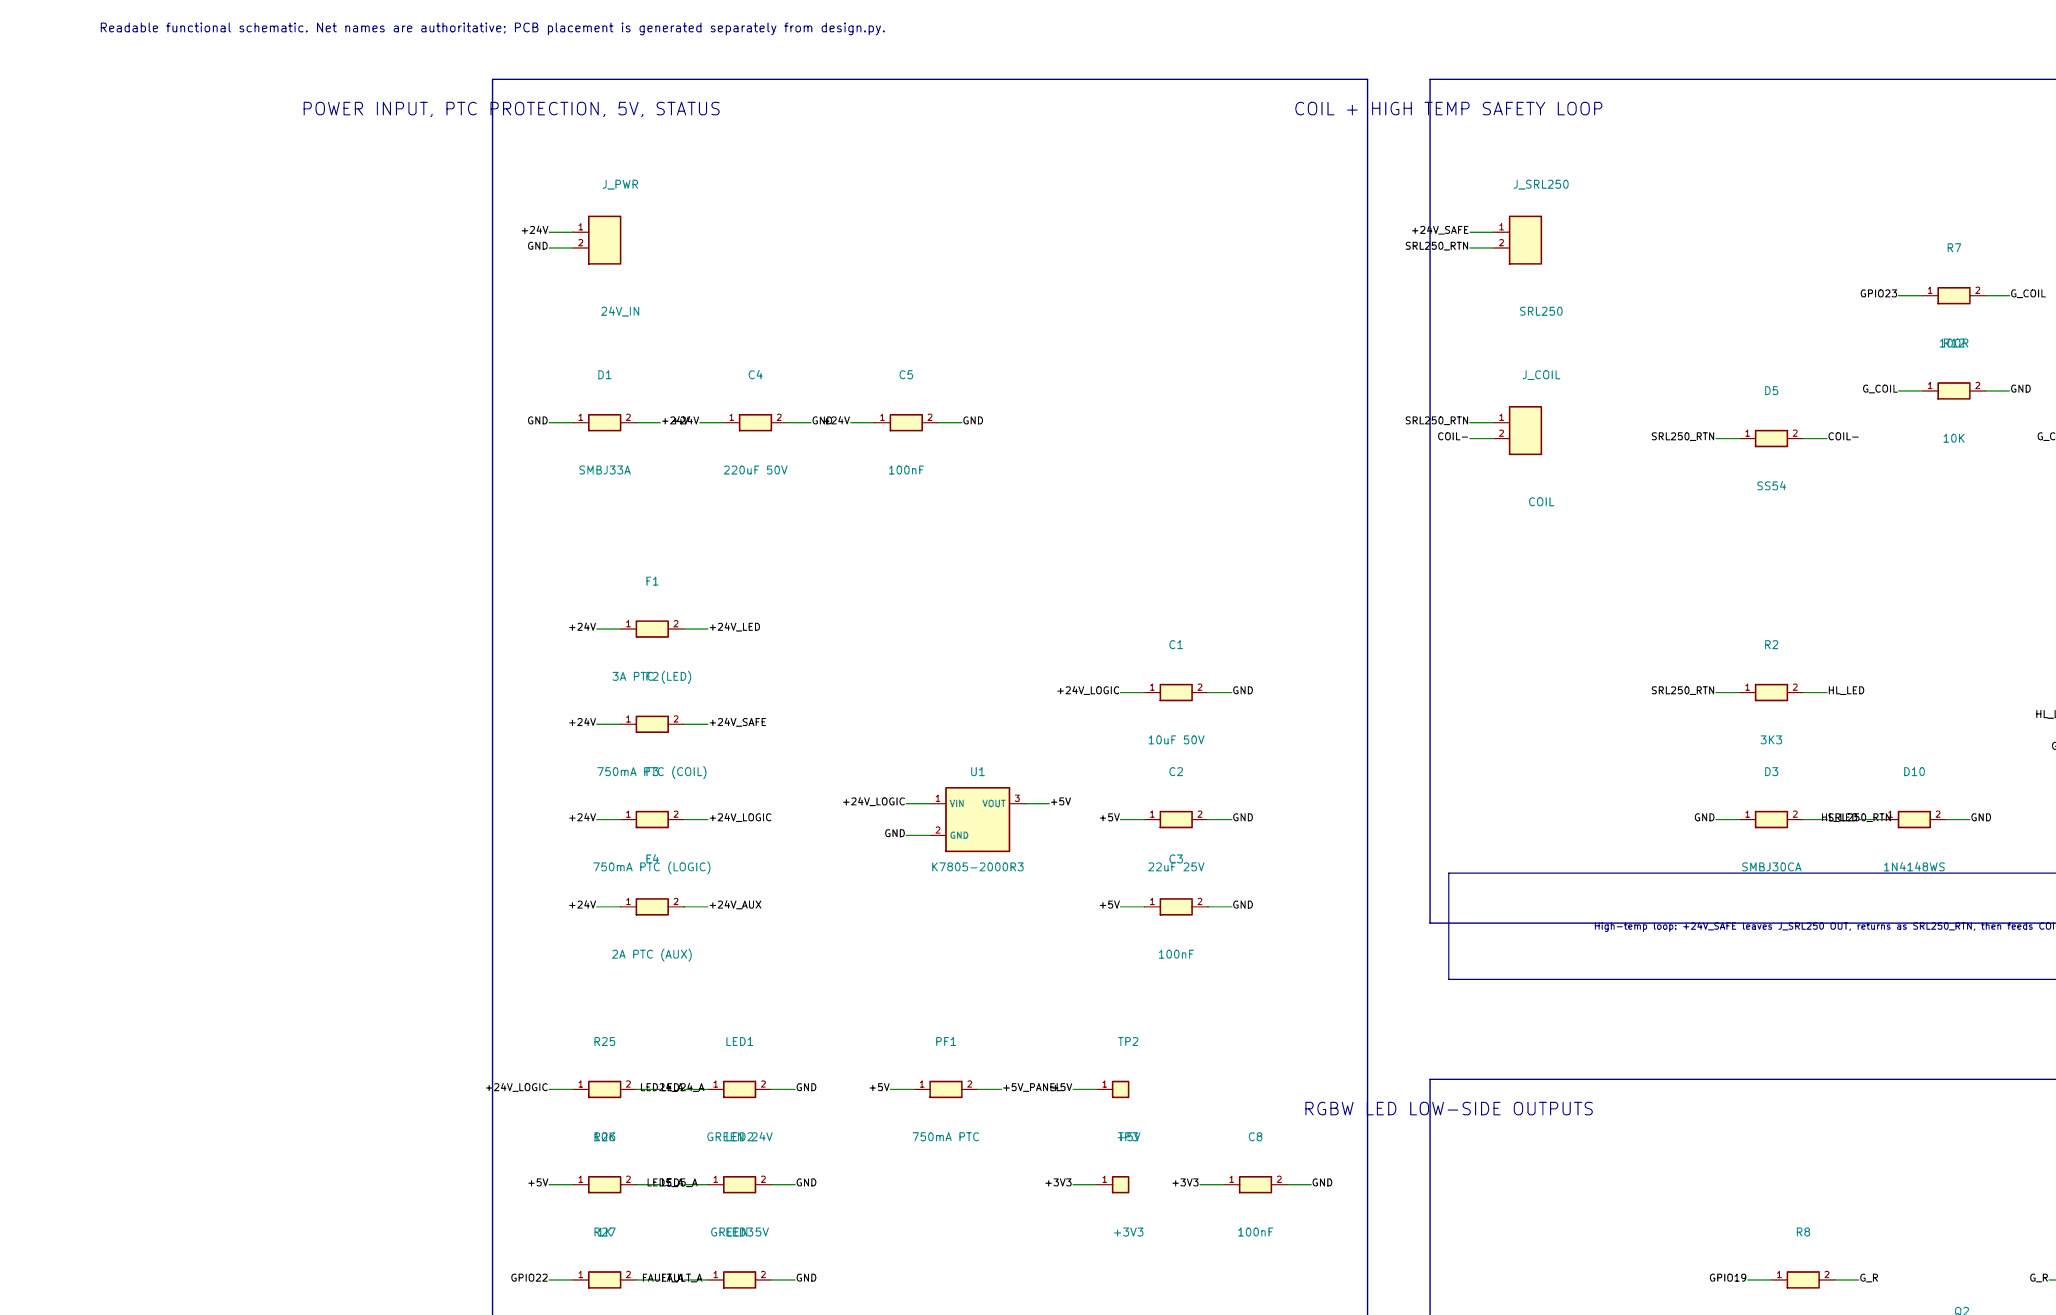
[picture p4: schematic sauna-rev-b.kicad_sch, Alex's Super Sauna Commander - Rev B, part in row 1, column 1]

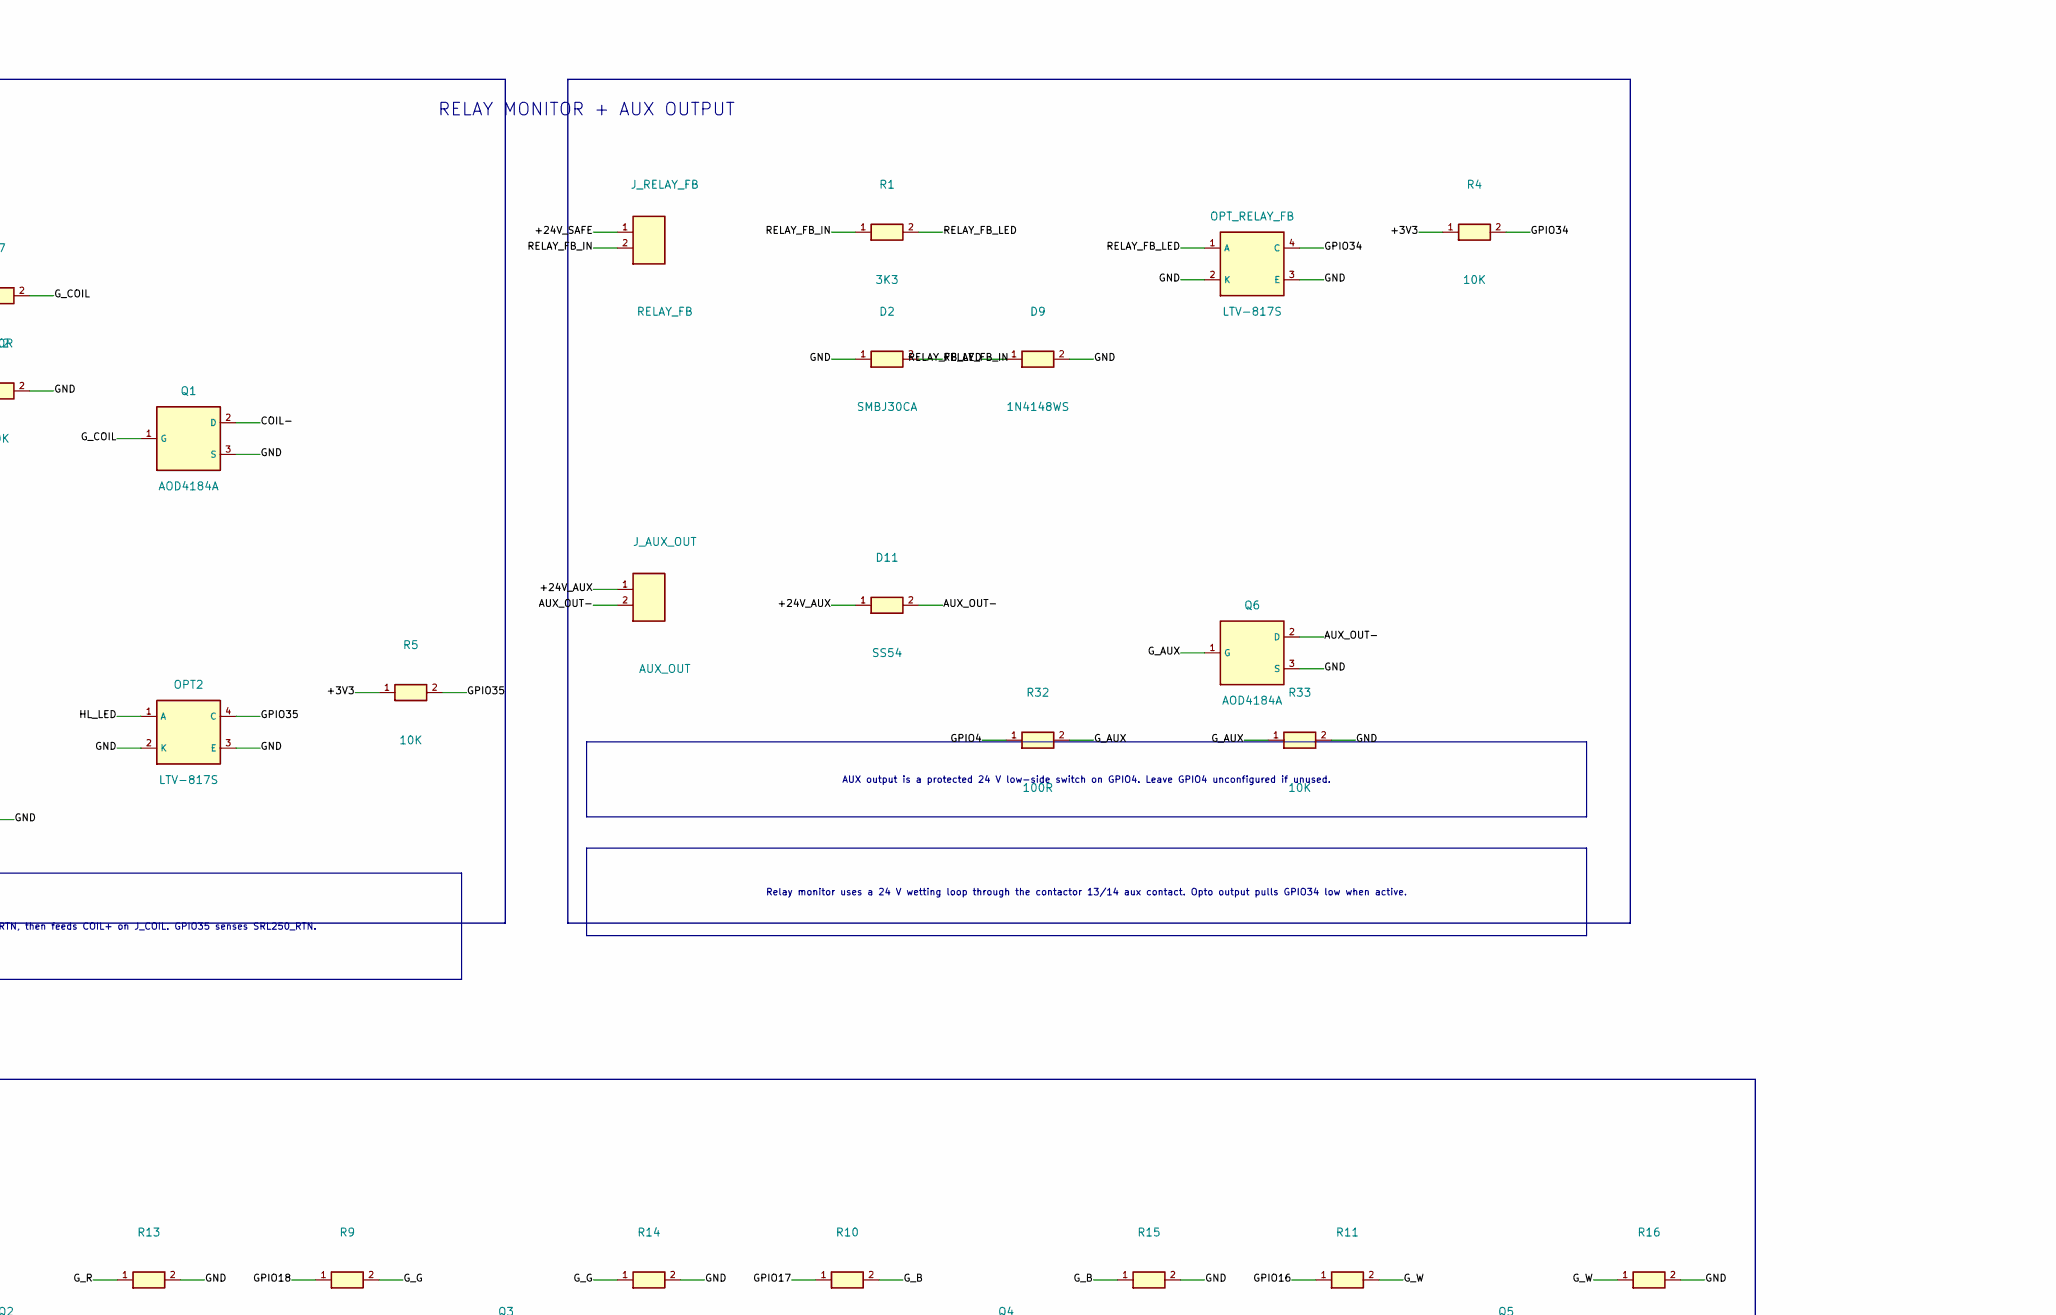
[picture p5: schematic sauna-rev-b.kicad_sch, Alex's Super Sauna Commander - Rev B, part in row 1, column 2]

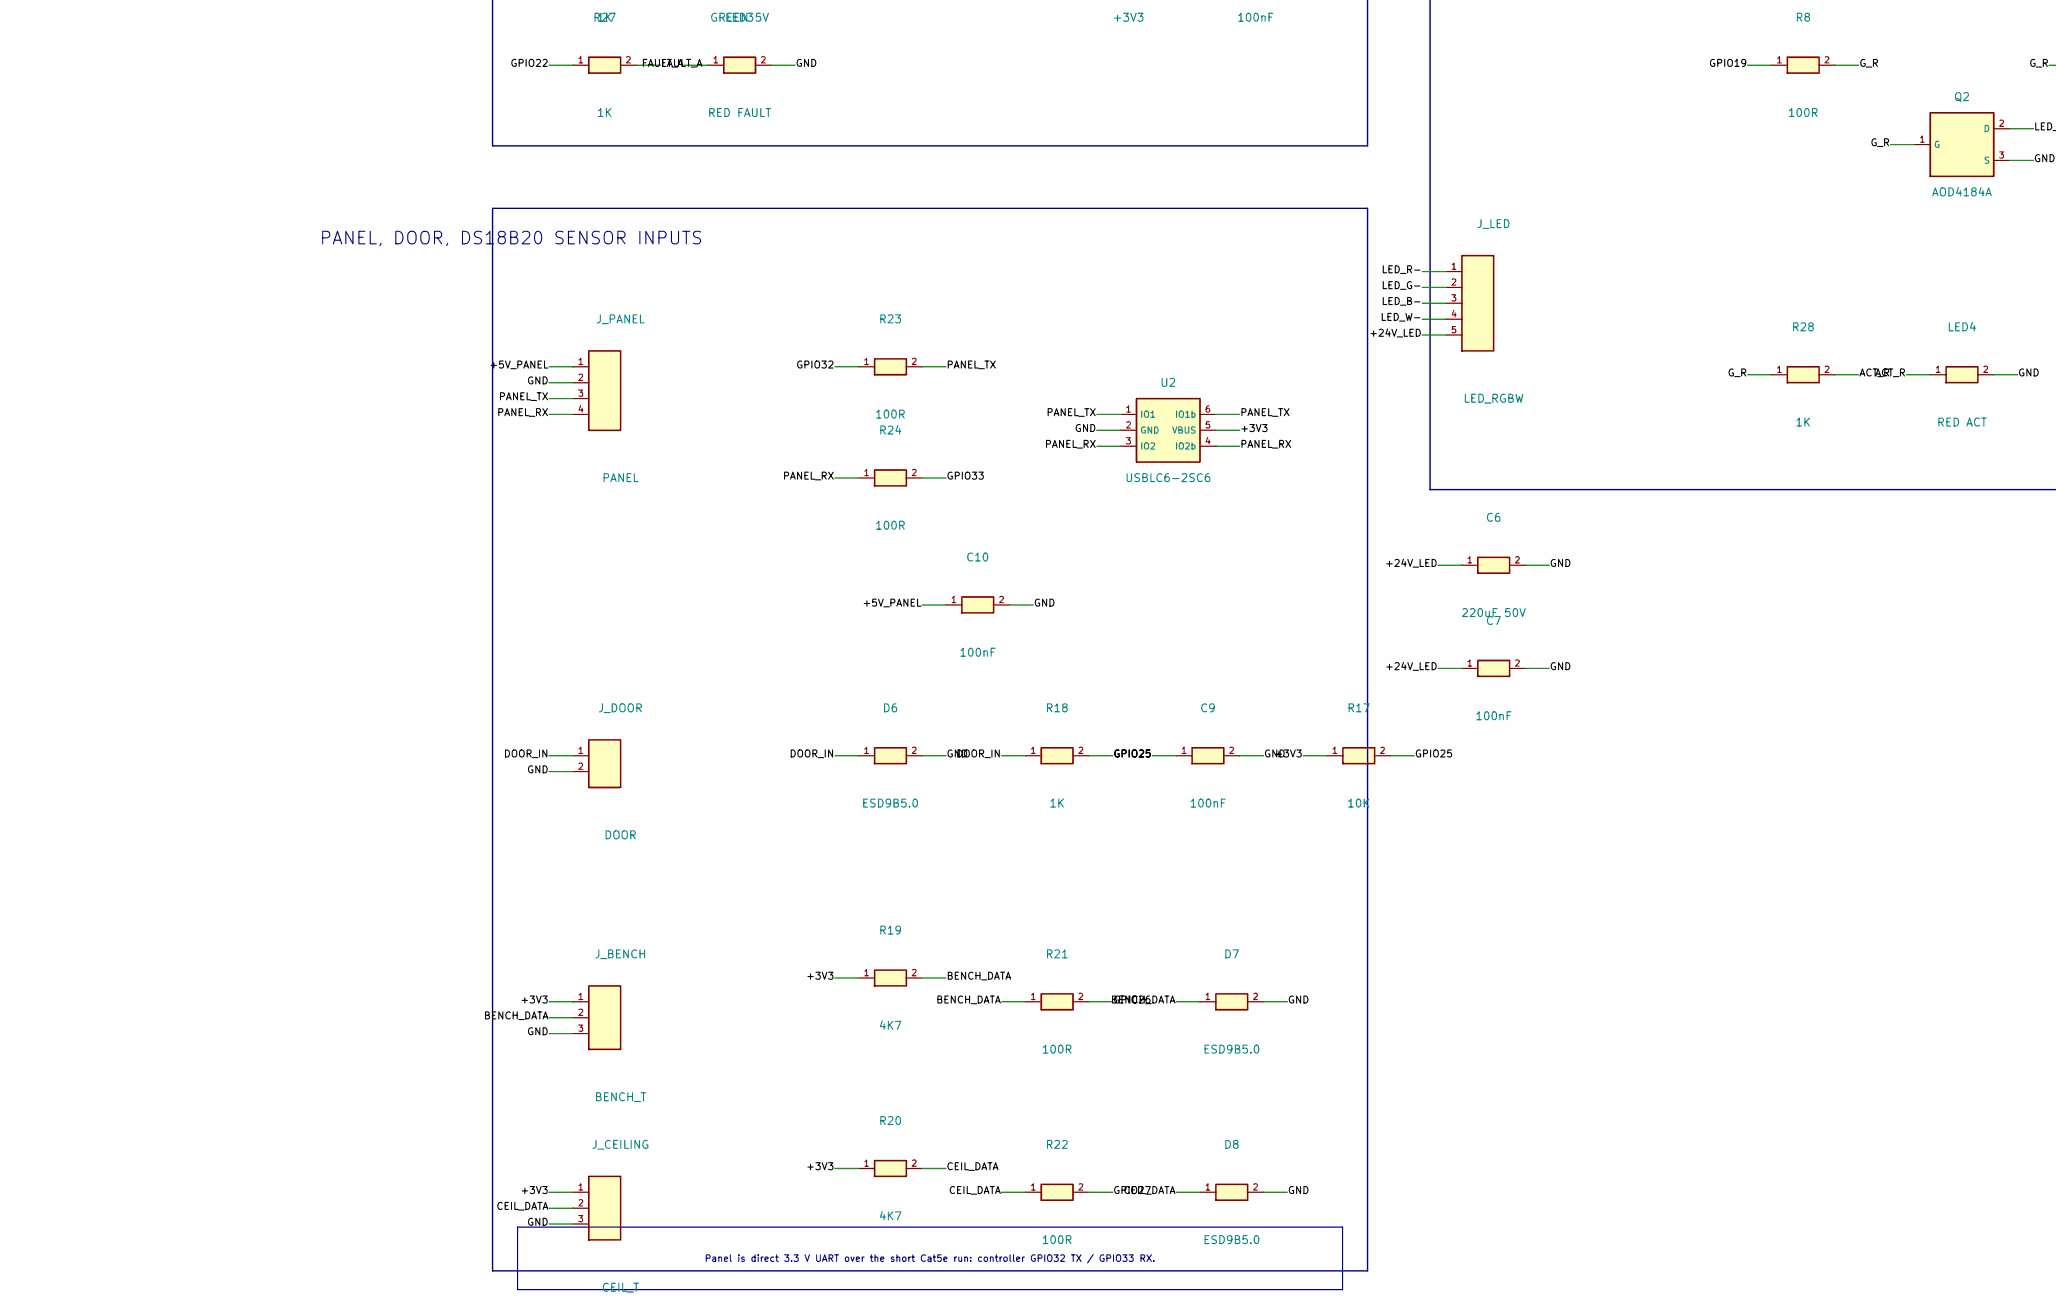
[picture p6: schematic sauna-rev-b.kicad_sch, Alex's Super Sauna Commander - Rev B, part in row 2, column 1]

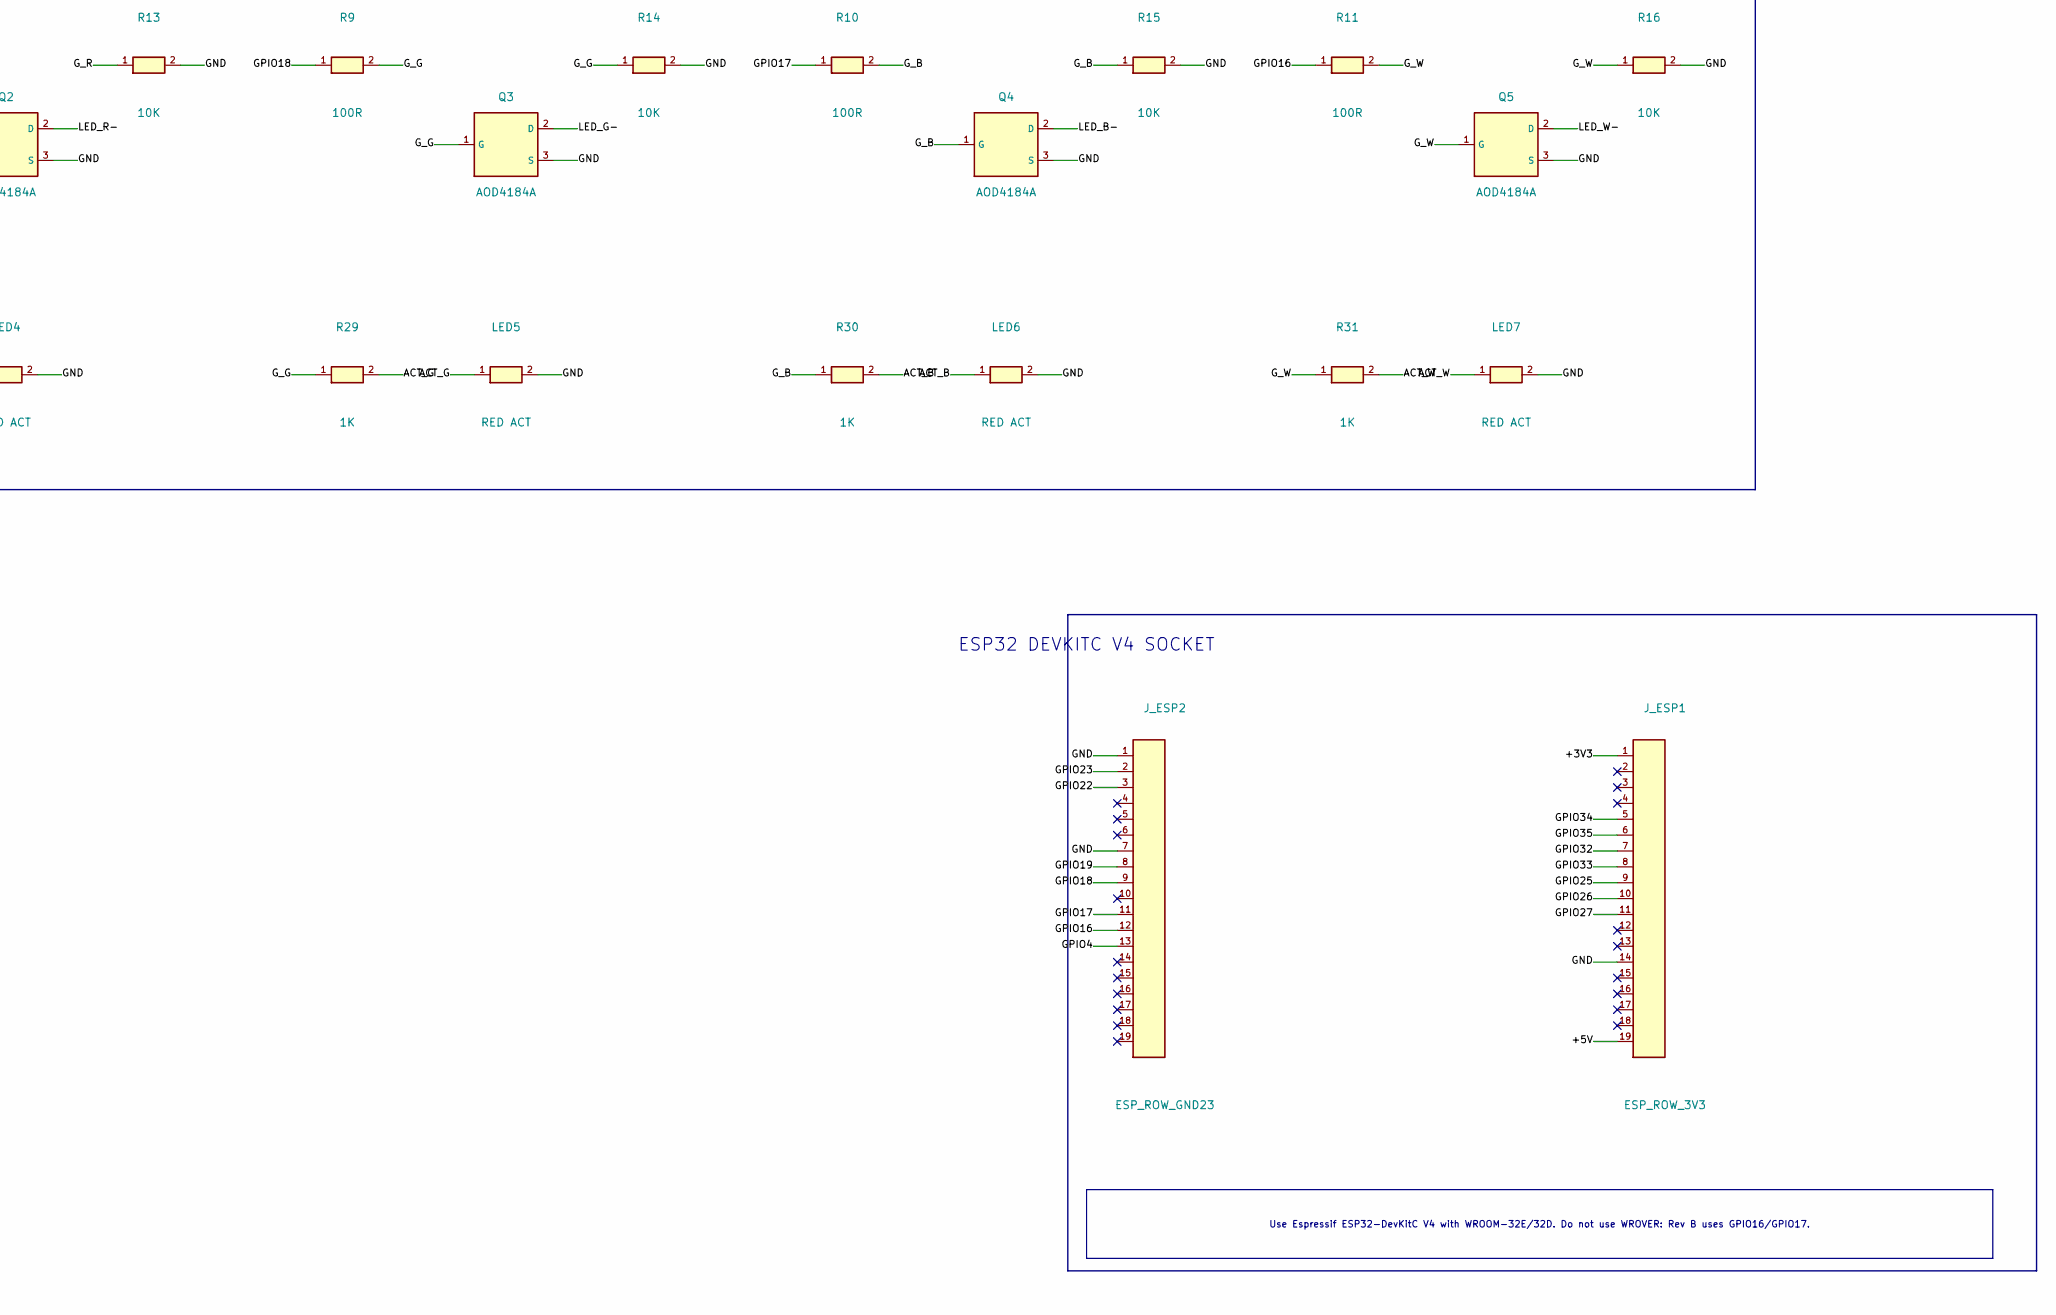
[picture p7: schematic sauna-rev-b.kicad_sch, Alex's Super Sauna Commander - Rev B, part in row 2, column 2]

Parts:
C1: 10uF 50V; C_1210; LCSC C138687
C2: 22uF 25V; C_1210; LCSC C52306
C3, C5, C7, C8, C9, C10: 100nF; C_0805; LCSC C49678
C4, C6: 220uF 50V; CP_D8_P3.5; LCSC C106658
D1: SMBJ33A; D_SMB; MPN SMBJ33A; LCSC C78419
D2, D3: SMBJ30CA; D_SMB; MPN SMBJ30CA; LCSC C5331115
D5, D11: SS54; D_SMA; MPN SS54; LCSC C22452
D6, D7, D8: ESD9B5.0; D_SOD923; MPN ESD9B5.0ST5G; LCSC C111566
D9, D10: 1N4148WS; D_SOD323; LCSC C2128
F1: 3A PTC (LED); PTC_2920; MPN JLC C719172; LCSC C719172
F2: 750mA PTC (COIL); PTC_1812; MPN Bourns MF-MSMF075/24-2 or equivalent; LCSC C208467
F3: 750mA PTC (LOGIC); PTC_1812; MPN Bourns MF-MSMF075/24-2 or equivalent; LCSC C208467
F4: 2A PTC (AUX); PTC_2920; MPN JLC C139284; LCSC C139284
J_AUX_OUT: AUX_OUT; MKDS_2; MPN Phoenix MKDS 1,5/2-5,08; LCSC C8461
J_BENCH: BENCH_T; MKDS_3; MPN Phoenix MKDS 1,5/3-5,08; LCSC C8438
J_CEILING: CEIL_T; MKDS_3; MPN Phoenix MKDS 1,5/3-5,08; LCSC C8438
J_COIL: COIL; MKDS_2; MPN Phoenix MKDS 1,5/2-5,08; LCSC C8461
J_DOOR: DOOR; MKDS_2; MPN Phoenix MKDS 1,5/2-5,08; LCSC C8461
J_ESP1: ESP_ROW_3V3; SOCKET_1x19; MPN PinSocket 1x19 2.54mm; LCSC C319202
J_ESP2: ESP_ROW_GND23; SOCKET_1x19; MPN PinSocket 1x19 2.54mm; LCSC C319202
J_LED: LED_RGBW; MKDS_5; MPN Phoenix MKDS 1,5/5-5,08; LCSC C8433
J_PANEL: PANEL; MKDS_4; MPN Phoenix MKDS 1,5/4-5,08; LCSC C8429
J_PWR: 24V_IN; MKDS_2; MPN Phoenix MKDS 1,5/2-5,08; LCSC C8461
J_RELAY_FB: RELAY_FB; MKDS_2; MPN Phoenix MKDS 1,5/2-5,08; LCSC C8461
J_SRL250: SRL250; MKDS_2; MPN Phoenix MKDS 1,5/2-5,08; LCSC C8461
LED1: GREEN 24V; LED_0805; LCSC C2297
LED2: GREEN 5V; LED_0805; LCSC C2297
LED3: RED FAULT; LED_0805; LCSC C2295
LED4, LED5, LED6, LED7: RED ACT; LED_0805; MPN red 0805; LCSC C2295
OPT2: LTV-817S; SOP4_OPTO; MPN LTV-817S; LCSC C109227
OPT_RELAY_FB: LTV-817S; SOP4_OPTO; MPN LTV-817S; LCSC C109227
PF1: 750mA PTC; R_1812; MPN MF-MSMF075/24X; LCSC C208467
Q1, Q2, Q3, Q4, Q5, Q6: AOD4184A; TO252; MPN AOD4184A; LCSC C99124
R1, R2: 3K3; R_1206; LCSC C104771
R4, R5, R12, R13, R14, R15, R16, R17, R25, R33: 10K; R_0805; LCSC C17414
R7, R8, R9, R10, R11, R21, R22, R23, R24, R32: 100R; R_0805; LCSC C17408
R18, R26, R27, R28, R29, R30, R31: 1K; R_0805; LCSC C17513
R19, R20: 4K7; R_0805; LCSC C17673
TP2: +5V; TESTPOINT
TP3: +3V3; TESTPOINT
U1: K7805-2000R3; SIP3_REG; MPN K7805-2000R3; LCSC C18212380
U2: USBLC6-2SC6; SOT23_6; MPN USBLC6-2SC6; LCSC C7519

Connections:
+3V3: C8.1, J_BENCH.1, J_CEILING.1, J_ESP1.1, R4.1, R5.1, R17.1, R19.1, R20.1, TP3.1, U2.5 (VBUS)
+5V: C2.1, C3.1, J_ESP1.19, PF1.1, R26.1, TP2.1, U1.3 (VOUT)
+5V_PANEL: C10.1, J_PANEL.1, PF1.2
+24V: C4.1, C5.1, D1.2, F1.1, F2.1, F3.1, F4.1, J_PWR.1
+24V_AUX: D11.1, F4.2, J_AUX_OUT.1
+24V_LED: C6.1, C7.1, F1.2, J_LED.5
+24V_LOGIC: C1.1, F3.2, R25.1, U1.1 (VIN)
+24V_SAFE: F2.2, J_RELAY_FB.1, J_SRL250.1
ACT_B: LED6.1, R30.2
ACT_G: LED5.1, R29.2
ACT_R: LED4.1, R28.2
ACT_W: LED7.1, R31.2
AUX_OUT-: D11.2, J_AUX_OUT.2, Q6.2 (D)
BENCH_DATA: D7.1, J_BENCH.2, R19.2, R21.1
CEIL_DATA: D8.1, J_CEILING.2, R20.2, R22.1
COIL-: D5.2, J_COIL.2, Q1.2 (D)
DOOR_IN: D6.1, J_DOOR.1, R18.1
FAULT_A: LED3.1, R27.2
GND: C1.2, C2.2, C3.2, C4.2, C5.2, C6.2, C7.2, C8.2, C9.2, C10.2, D1.1, D2.1, D3.1, D6.2, D7.2, D8.2, D9.2, D10.2, J_BENCH.3, J_CEILING.3, J_DOOR.2, J_ESP1.14, J_ESP2.1, J_ESP2.7, J_PANEL.2, J_PWR.2, LED1.2, LED2.2, LED3.2, LED4.2, LED5.2, LED6.2, LED7.2, OPT2.2 (K), OPT2.3 (E), OPT_RELAY_FB.2 (K), OPT_RELAY_FB.3 (E), Q1.3 (S), Q2.3 (S), Q3.3 (S), Q4.3 (S), Q5.3 (S), Q6.3 (S), R12.2, R13.2, R14.2, R15.2, R16.2, R33.2, U1.2 (GND), U2.2 (GND)
GPIO4: J_ESP2.13, R32.1
GPIO16: J_ESP2.12, R11.1
GPIO17: J_ESP2.11, R10.1
GPIO18: J_ESP2.9, R9.1
GPIO19: J_ESP2.8, R8.1
GPIO22: J_ESP2.3, R27.1
GPIO23: J_ESP2.2, R7.1
GPIO25: C9.1, J_ESP1.9, R17.2, R18.2
GPIO26: J_ESP1.10, R21.2
GPIO27: J_ESP1.11, R22.2
GPIO32: J_ESP1.7, R23.1
GPIO33: J_ESP1.8, R24.2
GPIO34: J_ESP1.5, OPT_RELAY_FB.4 (C), R4.2
GPIO35: J_ESP1.6, OPT2.4 (C), R5.2
G_AUX: Q6.1 (G), R32.2, R33.1
G_B: Q4.1 (G), R10.2, R15.1, R30.1
G_COIL: Q1.1 (G), R7.2, R12.1
G_G: Q3.1 (G), R9.2, R14.1, R29.1
G_R: Q2.1 (G), R8.2, R13.1, R28.1
G_W: Q5.1 (G), R11.2, R16.1, R31.1
HL_LED: D10.1, OPT2.1 (A), R2.2
LED5_A: LED2.1, R26.2
LED24_A: LED1.1, R25.2
LED_B-: J_LED.3, Q4.2 (D)
LED_G-: J_LED.2, Q3.2 (D)
LED_R-: J_LED.1, Q2.2 (D)
LED_W-: J_LED.4, Q5.2 (D)
PANEL_RX: J_PANEL.4, R24.1, U2.3 (IO2), U2.4 (IO2b)
PANEL_TX: J_PANEL.3, R23.2, U2.1 (IO1), U2.6 (IO1b)
RELAY_FB_IN: D2.2, J_RELAY_FB.2, R1.1
RELAY_FB_LED: D9.1, OPT_RELAY_FB.1 (A), R1.2
SRL250_RTN: D3.2, D5.1, J_COIL.1, J_SRL250.2, R2.1

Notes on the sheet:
High-temp loop: +24V_SAFE leaves J_SRL250 OUT, returns as SRL250_RTN, then feeds COIL+ on J_COIL. GPIO35 senses SRL250_RTN.
Relay monitor uses a 24 V wetting loop through the contactor 13/14 aux contact. Opto output pulls GPIO34 low when active.
AUX output is a protected 24 V low-side switch on GPIO4. Leave GPIO4 unconfigured if unused.
Use Espressif ESP32-DevKitC V4 with WROOM-32E/32D. Do not use WROVER: Rev B uses GPIO16/GPIO17.
Panel is direct 3.3 V UART over the short Cat5e run: controller GPIO32 TX / GPIO33 RX.
POWER INPUT, PTC PROTECTION, 5V, STATUS
COIL + HIGH TEMP SAFETY LOOP
RELAY MONITOR + AUX OUTPUT
RGBW LED LOW-SIDE OUTPUTS
PANEL, DOOR, DS18B20 SENSOR INPUTS
ESP32 DEVKITC V4 SOCKET
Readable functional schematic. Net names are authoritative; PCB placement is generated separately from design.py.

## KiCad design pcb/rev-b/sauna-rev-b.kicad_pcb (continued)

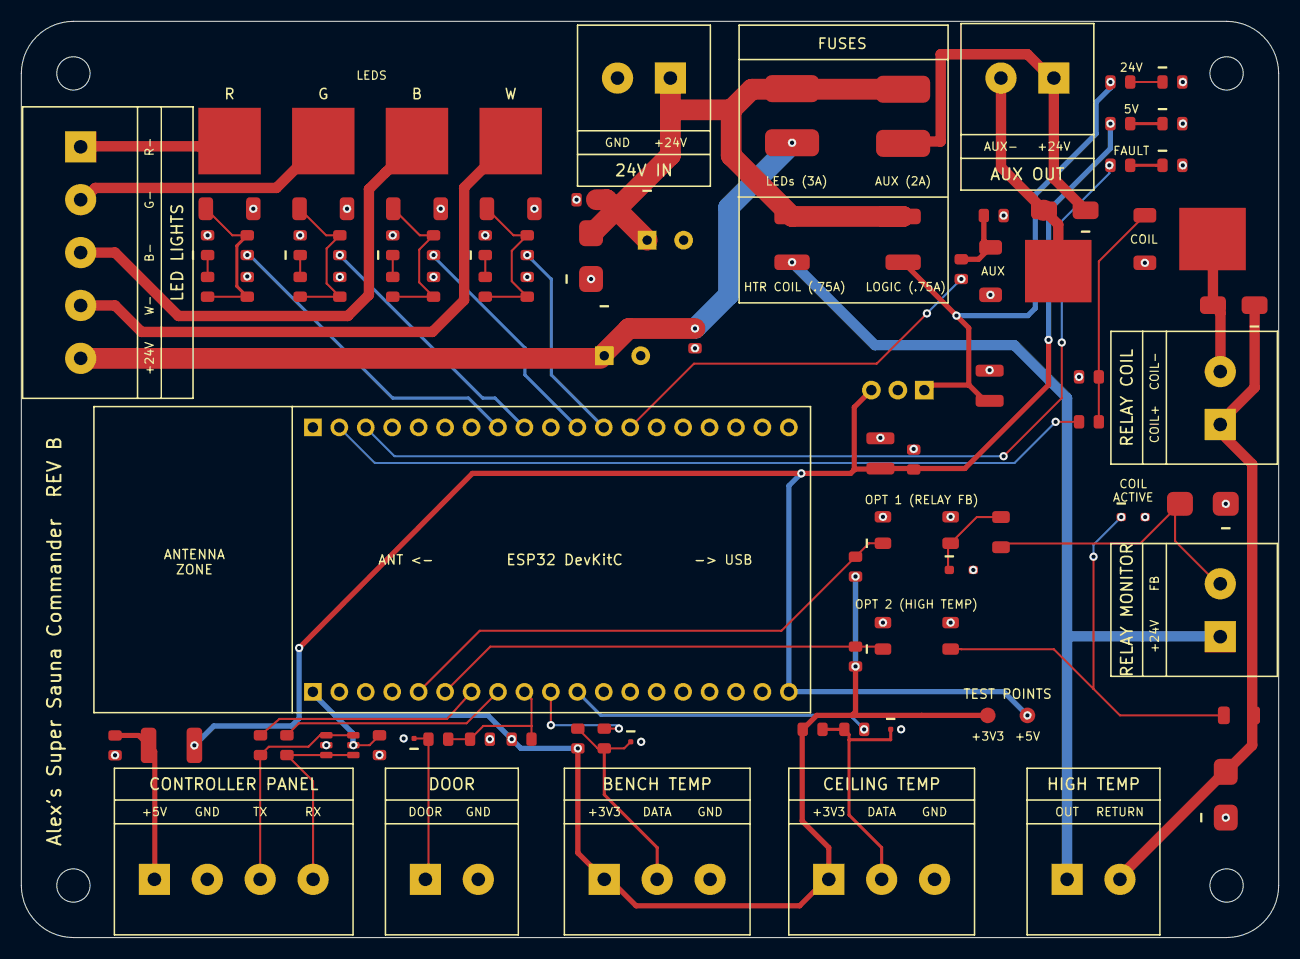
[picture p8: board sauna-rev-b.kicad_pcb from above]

Board: 2 copper layers, 120.8 x 88.0 mm, 91 parts (0 on the bottom side), 51 nets.

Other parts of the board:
H1, H2, H3, H4: M3; MountingHole_M3_NPTH

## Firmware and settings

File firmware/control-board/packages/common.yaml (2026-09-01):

esphome:
  name: ${device_name}
  friendly_name: ${friendly_name}
  project:
    name: sauna.open_controller
    version: "${controller_project_version}"

esp32:
  board: esp32dev
  framework:
    type: esp-idf
    sdkconfig_options:
      CONFIG_ESP_TASK_WDT: "y"
      CONFIG_ESP_TASK_WDT_TIMEOUT_S: "30"

logger:
  level: INFO
  baud_rate: 0

# Required for syslog
time:
  - platform: homeassistant
    id: ha_time

# Required for syslog - UDP client
udp:
  id: syslog_udp
  addresses: ${syslog_host}

# Remote syslog to VictoriaLogs via Alloy
syslog:
  udp_id: syslog_udp
  port: 5515
  level: INFO
  strip: true

ota:
  platform: esphome
  password: ${ota_password}

api:
  encryption:
    key: ${api_key}

wifi:
  ssid: ${wifi_ssid}
  password: ${wifi_password}
  ap:
    ssid: ${friendly_name}_AP
    password: ${wifi_fallback_pw}

web_server:
  port: 80
  
captive_portal:

############### GLOBALS ###############
globals:
  - id: fault_latched # Is The Sauna in Fault
    type: bool
    restore_value: no
    initial_value: "false"
  - id: last_trip_reason # Last Trip Reason
    type: std::string
    restore_value: no
    initial_value: ""
  - id: session_start_ms # Sauna Start Time
    type: uint32_t
    restore_value: no
    initial_value: "0"
  - id: session_active # Is Sauna in Use
    type: bool
    restore_value: no
    initial_value: "false"
  - id: door_open_since # Door Open Time
    type: uint32_t
    restore_value: no
    initial_value: "0"
  - id: welded_detect_since # Welded Contactor Trip Time
    type: uint32_t
    restore_value: no
    initial_value: "0"
  - id: coil_is_on # Track actual coil state for welded detection
    type: bool
    restore_value: no
    initial_value: "false"
  - id: fault_code_val # Numeric fault enum: 0=none, 1=door, 2=high temp, 3=welded
    type: uint8_t
    restore_value: no
    initial_value: "0"
  - id: staged_light_r # RGBW staging for coalesced apply
    type: float
    restore_value: no
    initial_value: "0"
  - id: staged_light_g
    type: float
    restore_value: no
    initial_value: "0"
  - id: staged_light_b
    type: float
    restore_value: no
    initial_value: "0"
  - id: staged_light_w
    type: float
    restore_value: no
    initial_value: "0"
  - id: light_apply_pending # Triggers coalesced RGBW light.control
    type: bool
    restore_value: no
    initial_value: "false"

number:
  - platform: template   # Door-open timeout before tripping (seconds)
    name: "Door Open Fault Seconds"
    id: door_open_fault_s
    min_value: 15
    max_value: 300
    step: 5
    optimistic: true
    restore_value: true
    initial_value: 45
  - platform: template  # Software high-temp trip (°F)
    name: "Software High Temp °F"
    id: soft_high_temp_f
    min_value: 190
    max_value: 230
    step: 1
    optimistic: true
    restore_value: true
    initial_value: 210

################### INPUTS ###################

binary_sensor:

# ----- Door Sensor -----
  - platform: gpio
    id: door_sensor
    name: "Sauna Door"
    device_class: door
    pin:
      number: ${door_pin}
      mode:
        input: true
        pullup: true
      inverted: false    # NO reed switch: closed pulls LOW, open pulls HIGH
    filters:
      - delayed_on: 100ms
      - delayed_off: 100ms
    on_state:
      then:
        - logger.log:
            format: "Door sensor changed to: %s"
            args: ['x ? "OPEN" : "CLOSED"']

# ----- Relay Feedback Status -----
  - platform: gpio
    id: ${feedback_sensor_id}
    name: "${feedback_sensor_name}"
    pin:
      number: ${feedback_pin}
      mode:
        input: true
        pullup: ${feedback_pullup}
    filters:
      - lambda: return !x;      # TRUE when relay feedback closed (opto pulls low)
      - delayed_on: 50ms
      - delayed_off: 50ms

# ----- High Limit Trip -----  
  - platform: gpio
    id: high_limit_trip
    name: "High Limit Trip"
    pin:
      number: ${high_limit_pin}
      mode:
        input: true
        pullup: ${high_limit_pullup}
    filters:
      - lambda: return x;      # opto ON (GPIO low) = loop OK; GPIO high = tripped
      - delayed_on: 100ms
      - delayed_off: 100ms

# Panel status exports (template binary sensors for packet_transport)
  - platform: template
    name: "Fault Latched"
    id: fault_latched_bs
    lambda: 'return id(fault_latched);'

  - platform: template
    name: "Heat Mode Active"
    id: heat_mode_active
    lambda: 'return id(sauna_thermostat).mode == climate::CLIMATE_MODE_HEAT;'

  - platform: template
    name: "Light On"
    id: light_on
    lambda: 'return id(sauna_light).current_values.is_on();'

# # ----- Future Opto Monitoring -----
#   - platform: gpio
#     id: future_monitoring
#     name: "Future Monitoring"
#     pin:
#       number: GPIO25
#       mode:
#         input: true
#         pullup: true
#     filters:
#       - lambda: return !x;      # TRUE when tripped (opto pulls low)
#       - delayed_on: 100ms
#       - delayed_off: 100ms
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

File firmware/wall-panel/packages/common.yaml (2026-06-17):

###############################################################################
# Wall Panel — CrowPanel 2.1" Common Config
# Shared UI, hardware, and interaction logic.
# Import this via packages/wifi.yaml or packages/wired.yaml.
###############################################################################

esphome:
  name: ${device_name}
  friendly_name: ${friendly_name}
  platformio_options:
    build_flags: "-DBOARD_HAS_PSRAM"
    board_build.esp-idf.memory_type: qio_opi
    board_build.flash_mode: dio
  on_boot:
    priority: 800
    then:
      # CrowPanel PCF8574 boot sequence — mandatory
      - output.turn_on: lcd_power
      - output.turn_on: display_reset
      - delay: 100ms
      - output.turn_off: display_reset
      - delay: 100ms
      - output.turn_on: tp_reset
      - delay: 100ms
      - output.turn_off: tp_reset
      - delay: 120ms
      - output.turn_on: tp_reset
      - delay: 120ms
      - output.turn_on: tp_intr

esp32:
  board: esp32-s3-devkitc-1
  framework:
    type: esp-idf
    sdkconfig_options:
      CONFIG_ESP32S3_DEFAULT_CPU_FREQ_240: "y"
      CONFIG_ESP32S3_DATA_CACHE_64KB: "y"
      CONFIG_SPIRAM_FETCH_INSTRUCTIONS: "y"
      CONFIG_SPIRAM_RODATA: "y"

psram:
  mode: octal
  speed: 80MHz

logger:
  level: INFO
  baud_rate: 0  # Free GPIO43/44 for the wired panel UART

wifi:
  ssid: ${wifi_ssid}
  password: ${wifi_password}

ota:
  platform: esphome
  password: ${ota_password}

############### GLOBALS ###############
globals:
  # Sync state
  - id: synced
    type: bool
    initial_value: "false"

  # Local mirrors — NaN = not yet synced
  - id: local_target_temp
    type: float
    initial_value: "NAN"
  - id: local_heat_mode
    type: float
    initial_value: "NAN"
  - id: local_brightness
    type: float
    initial_value: "NAN"
  - id: local_light_r
    type: float
    initial_value: "NAN"
  - id: local_light_g
    type: float
    initial_value: "NAN"
  - id: local_light_b
    type: float
    initial_value: "NAN"
  - id: local_light_w
    type: float
    initial_value: "NAN"

  # Interaction timestamps — suppress controller echo for 2s after user input
  - id: last_heater_interaction_ms
    type: uint32_t
    initial_value: "0"
  - id: last_brightness_interaction_ms
    type: uint32_t
    initial_value: "0"
  - id: last_color_interaction_ms
    type: uint32_t
    initial_value: "0"

  # One-shot action counters
  - id: clear_fault_ctr
    type: int
    initial_value: "0"
  - id: light_toggle_ctr
    type: int
    initial_value: "0"

  # Active preset (-1 = custom/unknown)
  - id: active_preset
    type: int
    initial_value: "-1"

  # Link state
  - id: last_rx_ms
    type: uint32_t
    initial_value: "0"
  - id: link_up
    type: bool
    initial_value: "false"

  # Active page tracker (0=main, 1=light, 2=info)
  - id: lv_active_page
    type: int
    initial_value: "0"

  # Status ring color (for cross-lambda access)
  - id: status_ring_color
    type: uint32_t
    initial_value: "0x555555"

  # Transport-agnostic state mirrors
  - id: fault_active
    type: bool
    initial_value: "false"
  - id: heater_running
    type: bool
    initial_value: "false"
  - id: current_temp
    type: float
    initial_value: "NAN"

  # Preset selection timestamp (debounce HA echo for WiFi)
  - id: preset_set_ms
    type: uint32_t
    initial_value: "0"

  # Transport-agnostic command flags
  - id: light_toggle_pending
    type: bool
    initial_value: "false"
  - id: clear_fault_pending
    type: bool
    initial_value: "false"
  - id: preset_pending
    type: int
    initial_value: "-1"

  # Light ring color (matches active preset)
  - id: light_ring_color
    type: uint32_t
    initial_value: "0xFF6B00"

############### CROWPANEL HARDWARE ###############

i2c:
  sda: GPIO38
  scl: GPIO39
  id: bus_a

pcf8574:
  - id: pcf
    address: 0x21

output:
  - platform: ledc
    pin: 6
    id: bl_pwm
    frequency: 19531Hz
  - platform: gpio
    id: lcd_power
    pin:
      pcf8574: pcf
      number: 3
      mode: { output: true }
      inverted: false
  - platform: gpio
    id: display_reset
    pin:
      pcf8574: pcf
      number: 4
      mode: { output: true }
      inverted: true
  - platform: gpio
    id: tp_reset
    pin:
      pcf8574: pcf
      number: 0
      mode: { output: true }
  - platform: gpio
    id: tp_intr
    pin:
      pcf8574: pcf
      number: 2
      mode: { output: true }

light:
  - platform: monochromatic
    name: "LCD Backlight"
    output: bl_pwm
    id: display_backlight
    default_transition_length: 0s
    restore_mode: ALWAYS_ON

spi:
  clk_pin: 2
  mosi_pin: 1

external_components:
  - source: github://sEbola76/Makerfabs
    components: [cst826]

touchscreen:
  platform: cst826
  id: panel_touch
  i2c_id: bus_a
  skip_probe: true
  update_interval: 50ms
  address: 0x15
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

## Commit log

2025-08-11 Add initial ESP Firmware
    Create sauna-controller.yaml with the firmware configuration for the ESP board
    [sauna-controller.yaml]
2025-08-16 Update sauna-controller.yaml
    Fixed platform specific issues and validated in ESPHome
    [sauna-controller.yaml]
2025-08-16 Move connections off strapped GPIO Pins
    [sauna-controller.yaml]
2025-09-27 Update sauna-controller.yaml
    final working code - fixed temp sensor issues and updated GPIO pin locations for cleanest wiring
    [sauna-controller.yaml]
2025-09-27 Update wiring plan & notes in README
2025-09-30 extend thermostat cycle times
    changed thermostant min cycle time from 2 minutes > 5 minutes to prevent unnecessary wear on heater
    [sauna-controller.yaml]
2025-11-07 change from PT100s to DS18B20 Temp Sensors
    [sauna-controller.yaml]
2025-11-11 Update sauna-controller.yaml to reflect updating wiring
    [sauna-controller.yaml]
2025-11-11 Add "final" version of code
    mostly final code with all core features and safeties enabled
    [sauna-controller.yaml]
2025-11-12 Update README.md
    moved door sensor to pin 22
2026-03-29 CrowPanel firmware: Nest-inspired UI, WiFi/wired transport split, HA integration
    Complete panel firmware redesign with working bidirectional control:
    UI:
    - Nest thermostat-inspired dark theme with 36px ring, 96px light-weight temp display
    - 3-page layout: heater (temp + status ring), lights (4 color preset circles), status
    - Ring color reflects heater state (gray=off, blue=standby, orange=heating, green=target)
    - Light page ring color matches active light preset, brightness via arc fill
    - Page navigation via tap zone in ring gap at bottom
    - Encoder: rotate=adjust temp/brightness, click=set/toggle, long press=off
    Transport:
    - Split into common + wifi + wired YAML via ESPHome packages
    - saun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
    [sauna-controller.yaml]
2026-03-29 Update README with wall panel documentation
    Add comprehensive Wall Panel section covering hardware, UI design,
    interaction model, firmware architecture, build instructions, and
    wiring. Update intro to reflect panel is now in active development.
    Update ESP32 pinout with panel UART pins (GPIO14/GPIO4).
2026-03-29 Add controller transport contract, fix status model, optimize wired path
    Controller (sauna-controller.yaml):
    - Add UART (GPIO14/GPIO4) + packet_transport for panel communication
    - Export 9 sensors + 6 binary_sensors to panel via packet_transport
    - Add command consumers with validation (temp clamp, NaN reject, mode dedup)
    - RGBW coalescing: stage 4 channels, apply in one light.control call (100ms)
    - Add fault_code_val global (0=none, 1=door, 2=high temp, 3=welded)
    Panel common (sauna-panel-common.yaml):
    - Restore AT TARGET status (green ring when within 2°F of target)
    - Handle NaN boot state (show "---" before first sync)
    - Add current_temp global for transport-agnostic temp comparison
    - Pa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
    [sauna-controller.yaml]
2026-03-29 Simplify wired comms: timestamp model replaces dirty flags
    Replace the entire dirty flag / echo-back / fire-and-forget state machine
    with 3 simple interaction timestamps. When the user interacts, the panel
    updates the display instantly and sends commands for 2 seconds. After 2s
    of no interaction, controller truth takes over. No oscillation possible.
    Changes:
    - Remove all dirty flags (target_temp_dirty, heat_mode_dirty, etc.)
    - Remove echo-back matching, fire-and-forget timers, auto-clear logic
    - Add 3 timestamps: last_heater/brightness/color_interaction_ms
    - Command sensors publish values for 2s after interaction, then NaN
    - Consumed sensor handlers suppress echo for 2s after interaction
    -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
    [sauna-controller.yaml]
2026-04-11 Heater rotation auto-sends when on, light brightness turns on LEDs
    - Encoder rotation on heater page now sends target temp immediately
    when heat mode is on; previews locally when off (confirm via click)
    - Controller cmd_light_brightness explicitly sets state so rotating
    the brightness encoder turns on the lights when they're off
    [sauna-controller.yaml]
2026-06-11 Document PCB bring-up notes
2026-06-17 chore(pcb): archive Rev A board files
    [jlc-assembly-selection.csv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]
2026-06-17 feat(pcb): add Rev B control board design
    [sauna-rev-b.kicad_pcb, sauna-rev-b.kicad_sch]
2026-06-17 chore(pcb): add Rev B fabrication outputs
    [sauna-rev-b-B_Cu.gbr, sauna-rev-b-B_Mask.gbr, sauna-rev-b-B_Paste.gbr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]
2026-06-17 feat(firmware): split Rev B control board and wall panel configs
    [rev-b-hardware.yaml]
2026-06-17 chore(pcb): refresh Rev B fabrication outputs
    [sauna-rev-b-B_Cu.gbr, sauna-rev-b-B_Mask.gbr, sauna-rev-b-B_Paste.gbr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]
2026-09-01 fix: ignore replayed panel action counters
    [common.yaml]
